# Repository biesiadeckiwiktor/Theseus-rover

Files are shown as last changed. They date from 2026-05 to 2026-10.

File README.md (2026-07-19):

# Theseus Rover

**A low-cost, open-source 6-wheeled rover platform for education, research, and DIY robotics.**

Theseus is inspired by planetary exploration rovers such as ESA's Rosalind Franklin (ExoMars) and CSA's MESR and REX. It can be built entirely from 3D-printed parts and components that are widely available worldwide — no machining or custom PCBs required.

- **Total cost:** under **$800 / £600**, *including* the cost of a 3D printer
- **Two steering configurations:** assemble as 4-wheel-steer (4WS) or 6-wheel-steer (6WS) using the same set of printed parts
- **Modular chassis** built from 2020 aluminium extrusion, so it's easy to extend with sensors, cameras, or a robotic arm

<div align="center">

Theseus rover performing a zero-radius turn
<br><br>
Theseus rover, front three-quarter view
Theseus rover, side view showing suspension

</div>

## Features

- **6-wheel drive** — six JGA25-370 geared DC motors with encoders (one per wheel)
- **4WS / 6WS steering** — four MG996R metal-gear servos steer the corner wheels; differential (Ackermann-style) steering geometry is computed on-board so all wheels track the correct turning radius
- **Zero-radius turning** — spin on the spot at the press of a button
- **Custom handheld transmitter** — dual joysticks, keypad, LCD with live signal strength, and a 3D-printed enclosure (~£76 in parts, design files included); supports the same Wi-Fi / HC-12 dual-mode link as the rover
- **Two radio link options** — control over Wi-Fi (UDP, Pico acts as an access point) or long-range 433 MHz using an HC-12 module; switch with a single flag in the firmware
- **12V LiFePO4 power** with DC-DC converters for logic and servo rails
- **Printable wheels** — uses Lego 32298 tyres, with a fully 3D-printed alternative included (coming soon)

## How it works

```
Theseus transmitter (custom handheld, Pico 2 W)
  dual joysticks · 4x4 keypad · 16x2 LCD · signal & battery indicators
        │
        │  Wi-Fi (UDP) or HC-12 433 MHz radio
        ▼
Raspberry Pi Pico 2 W (on rover)  ──  receives control packets, forwards over UART
        │
        ▼
Arduino Uno R3  ──  decodes packets, computes steering geometry (diffSteer library)
        │
        ├── 2× Adafruit Motor Shields  → 6× DC drive motors
        └── Adafruit 16-ch PWM Shield  → 4× steering servos
```

The `diffSteer` library (in `arduino_code/`) takes the rover's wheelbase and track widths and calculates the individual wheel speeds and steering angles needed for smooth, skid-free turns.

### Control packet format

The transmitter sends an 11-byte packet at ~10 Hz. Anyone can write their own controller (phone app, PC gamepad script, etc.) by sending this frame over UDP to the rover's access point (`192.168.4.1:5005`) or over an HC-12 serial link:

| Byte | Content |
|---|---|
| 0 | Start marker `0xAA` |
| 1–3 | Joystick 1 axes (0–255) |
| 4–6 | Joystick 2 axes (0–255) |
| 7–9 | Button states (24-bit bitmask: 16 keypad keys + 2 joystick buttons) |
| 10 | End marker `0x55` |

## Repository contents

| Path | Description |
|---|---|
| `CAD files/` | All 3D-printable and laser-cut parts in STEP format |
| `arduino_code/` | Arduino Uno firmware: packet decoding, motor/servo control, and the `diffSteer` steering-geometry library |
| `pico_code/` | Raspberry Pi Pico 2 W firmware (MicroPython): Wi-Fi/HC-12 receiver bridge |
| `transmitter/` | Custom handheld transmitter: MicroPython firmware, 3D-printable enclosure (STEP), and its own bill of materials |
| `Bill of materials.xlsx` | Full costed parts list with supplier links |

## The transmitter

Theseus is driven with a purpose-built handheld transmitter (~£76 in parts) rather than an off-the-shelf gamepad:

- **Dual 4-axis joysticks** sampled by two ADS1115 16-bit ADCs over I2C
- **4×4 matrix keypad** for mode switching and auxiliary functions (e.g. zero-turn toggle)
- **16×2 LCD** showing connection status and a live signal-strength bar graph (RSSI)
- **Battery level LEDs** (4-stage indicator)
- **3D-printed enclosure** — CAD in `transmitter/cad/`
- Automatic reconnection if the radio link drops

See `transmitter/bill of materials transmitter.ods` for the full parts list.

## Getting started

### 1. Print and source the parts

Open `Bill of materials.xlsx` for the complete parts list with prices and links. All structural parts in `CAD files/` are provided as STEP files — slice and print them in PLA or PETG. 

All parts were printed with 3 wall loops and 20% infill. 

Structural integrity was tested with static weight of 60kg and no isses were observed, although for normal use up to 15kg is recommended depending on terrain due to limited motor power.

### 2. Assemble

The chassis is built around 2020 aluminium extrusion with printed brackets, joints, and covers. Choose 4WS or 6WS during assembly — both use the same printed parts.

Full assembly guide coming soon

### 3. Flash the firmware

**Raspberry Pi Pico 2 W** (radio receiver):
1. Install MicroPython on the Pico
2. Copy `pico_code/main.py` to the board
3. Set `USE_WIFI = True` for Wi-Fi control or `False` for HC-12

**Arduino Uno** (motion controller):
1. Open `arduino_code/arduino_code.ino` in the Arduino IDE
2. Install the required libraries: `Adafruit Motor Shield V2`, `Adafruit PWM Servo Driver`
3. Upload to the board

### 4. Build and flash the transmitter

1. Source the parts in `transmitter/bill of materials transmitter.ods` (~£76) and print the enclosure from `transmitter/cad/`
2. Install MicroPython on the transmitter's Pico 2 W
3. Install the two required libraries by copying them to the board alongside the code:
   - [`ads1x15`](https://github.com/robert-hh/ads1x15) — driver for the ADS1115 ADCs that read the joysticks
   - [`DIYables_MicroPython_LCD_I2C`](https://github.com/DIYables/DIYables_MicroPython_LCD_I2C) — driver for the 16×2 I2C LCD (also available via Thonny's package manager)
4. Copy `transmitter/code/main.py` to the board
5. Set `USE_WIFI` at the top of the file to match the rover (`True` = Wi-Fi, `False` = HC-12). For Wi-Fi mode, also fill in the rover's IP address

> **Note:** if you use Wi-Fi mode, change the default access point password (`AP_PASSWORD` in `pico_code/main.py` and `PASSWORD` in the transmitter code) — anyone in range who knows the default could connect and send drive commands.

### 5. Drive

Power on the rover, then the transmitter — it connects to the rover's Wi-Fi access point automatically and reconnects if the link drops. One joystick controls speed, the other steering; the keypad handles auxiliary functions such as zero-turn mode.

## Contributing

Contributions, bug reports, and build logs are very welcome! If you build a Theseus, please open an issue or discussion with photos — it helps others and improves the docs.

## License

Code is released under the MIT License. Hardware design files are released under CERN-OHL-P / CC BY-SA 4.0.

## Acknowledgements

Design inspired by ESA's Rosalind Franklin (ExoMars) rover and the Canadian Space Agency's MESR and REX rover prototypes.

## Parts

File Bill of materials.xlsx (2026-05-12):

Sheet: 3-bogie 4WS
Theseus - bill of material | Incl. Shipping, at the time of compiling list
 | Price of individual parts of a kit is calculated as price / number of items
Component | Quantity | Unit price | Price | Comment |  | URL
Wheels
Lego 32298 Tire | 6 | £4.5000 | £27.0000 | 3D printed equivalent provided as alternative, this will reduce number of M3x12 cap srews and M3x4x5 inserts by 60 each |  | https://www.bricklink.com/v2/catalog/catalogitem.page?P=32298#T=S&C=11&O={"color":11,"iconly":0}
Motors
JGA25-370 DC Motor with encoder 6V 60 RPM | 6 | £5.5750 | £33.4500 | higher rpm motors not recommended |  | https://www.aliexpress.com/item/1005008766288833.html
Hex shaft coupling S:12mm L:18mm D:M4 | 6 | £1.1300 | £6.7800 |  |  | https://www.aliexpress.com/item/32794944304.html
Steering
TowerPro Servo Motor - MG996R 180° (Metal Gear) | 4 | £9.0000 | £36.0000 | or equivalent |  | https://thepihut.com/products/towerpro-servo-motor-mg996r-metal-gear-180
Battery
12V 6Ah LiFePO4 Battery | 1 | £19.9900 | £19.9900 | Any battery that fits in boxed volume of 75mm x 190mm x 110mm can be fitted inside the rover with modification to battery compartment
Electronics
Adafruit 16-Channel 12-bit PWM/Servo Shield - I2C interface | 1 | £16.80 | £16.8000 |  |  | https://thepihut.com/products/adafruit-16-channel-12-bit-pwm-servo-shield-i2c-interface
Adafruit Motor/Stepper/Servo Shield for Arduino v3 Kit | 2 | £19.20 | £38.4000 |  |  | https://thepihut.com/products/adafruit-motor-stepper-servo-shield-for-arduino-v2-kit-v2-3
ELEGOO UNO R3 | 1 | £12.10 | £12.1000 |  |  | https://www.amazon.co.uk/ELEGOO-Arduino-Arduino-Compatible-Transfer-Operation/dp/B09JWFTZ2V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
Raspberry Pi Pico 2 W (with headers) | 1 | £7.70 | £7.7000 |  |  | https://thepihut.com/products/raspberry-pi-pico-2-w?variant=54063378760065
High Efficiency Power Module 24V12V to 5V 5A DCDC Stepdown Power Converter | 1 | £5.23 | £5.2300 |  |  | https://www.ebay.co.uk/itm/205165861587?_skw=5v+5a+dcdc+converter&itmmeta=01KKAQXR24Q1MPMFQJWFVYTDKJ
DC-DC Adjustable Step-down Buck Converter Module 12V-75V to 5/24/48V 600W 25A | 1 | £10.9500 | £10.9500 | or equivalent |  | https://www.ebay.co.uk/itm/156755864763
Half-Size Breadboard - White | 1 | £3.0000 | £3.0000 |  |  | https://thepihut.com/products/raspberry-pi-breadboard-half-size
Hardware and fasteners
M3 X 12 Stainless Steel Hex Socket Cap Screw | 60 | £0.0179 | £1.0740 |  |  | https://www.amazon.co.uk/Assortment-Stainless-Replacement-Machine-Fastener/dp/B0B3MGZ7T2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
M3x4x5 threaded insert | 92 | £0.0432 | £3.9714 |  |  | https://www.amazon.co.uk/PATIKIL-Threaded-Knurled-Printing-Components/dp/B0DJ8YBQK8
M3 X 8 Stainless Steel Hex Socket Cap Screw | 16 | £0.0179 | £0.2864 |  |  | https://www.amazon.co.uk/Assortment-Stainless-Replacement-Machine-Fastener/dp/B0B3MGZ7T2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
M3 X 10 Stainless Steel Hex Socket Cap Screw | 44 | £0.0179 | £0.7876 |  |  | https://www.amazon.co.uk/Assortment-Stainless-Replacement-Machine-Fastener/dp/B0B3MGZ7T2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
M3 X 40 Stainless Steel Hex Socket Cap Screw | 4 | £0.0179 | £0.0716 |  |  | https://www.amazon.co.uk/Assortment-Stainless-Replacement-Machine-Fastener/dp/B0B3MGZ7T2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
M3 X 30 Stainless Steel Hex Socket Cap Screw | 16 | £0.0179 | £0.2864 |  |  | https://www.amazon.co.uk/Assortment-Stainless-Replacement-Machine-Fastener/dp/B0B3MGZ7T2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
M3 Nut | 41 | £0.0179 | £0.7339 |  |  | https://www.amazon.co.uk/Assortment-Stainless-Replacement-Machine-Fastener/dp/B0B3MGZ7T2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
Pan Head Brass Screw M4 x 12mm | 6 | £0.0300 | £0.1800 | can be replaced with steel M4x12 |  | https://www.toolstation.com/pan-head-brass-screw/p53904?store=MB&gad_source=1&gad_campaignid=17806929345
M3 X 6 Stainless Steel Hex Socket Cap Screw | 12 | £0.0179 | £0.2148 |  |  | https://www.amazon.co.uk/Assortment-Stainless-Replacement-Machine-Fastener/dp/B0B3MGZ7T2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
Miniature self-tapping crosshead metal screws M1.4 X 5 | 32 | £0.0099 | £0.3171 |  |  | https://www.aliexpress.com/item/1005009816599127.html?pdp_ext_f=%7B"order"%3A"-1"%2C"eval"%3A"1"%2C"fromPage"%3A"search"%7D&pdp_npi=6%40dis%21GBP%2110.39%2110.39%21%21%2194.37%2194.37%21%40210384b917690434802528240eb28d%2112000050263367998%21sea%21UK%216332233678%21X%211%210%21n_tag%3A-29919%3Bd%3A6fe90632%3Bm03_new_user%3A-29895&curPageLogUid=0YpVV11Uw3Cl&utparam-url=scene%3Asearch%7Cquery_from%3A%7Cx_object_id%3A1005009816599127%7C_p_origin_prod%3A
Bearing 25x37x7mm | 8 | £1.5590 | £12.4720 |  |  | https://www.amazon.co.uk/sourcing-map-25x37x7mm-Precision-Lubricated/dp/B0D756WMN6?cv_ct_cx=25id%2Bbearing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
6000-2RS Deep Groove Ball Bearings, ID 10mm x OD 26mm x Width 8mm | 6 | £0.9990 | £5.9940 |  |  | https://www.amazon.co.uk/HiPicco-6000-2RS-Bearings-Bearing-Pre-Lubricated/dp/B0CH2XRNGJ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
2020 aluminium extrusion 1m | 4 | £6.0300 | £24.1200 |  |  | https://www.ebay.co.uk/itm/352816257597?var=622098429634
2020 Cast Aluminium V-Slot Extrusion L Shape Corner Joint Right Angle Bracket-UK | 28 | £0.1838 | £5.1464 |  |  | https://www.ebay.co.uk/itm/227210906598?var=526410016032
M5 Sliding T Nuts | 137 | £0.0869 | £11.9053 |  |  | https://www.amazon.co.uk/PATIKIL-Fastener-European-Standard-Extrusion/dp/B0DS2KLZ5L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
Button Head Screws Hex Allen Socket Bolts Stainless Steel M5x10mm | 56 | £0.0984 | £5.5104 |  |  | https://www.ebay.co.uk/itm/256844204399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
Stainless Steel Washers Flat Heavy Thin Thick Wide M5 | 16 | £0.0425 | £0.6800 |  |  | https://www.ebay.co.uk/itm/167710376070?var=467313689508
Button Head Screws Hex Allen Socket Bolts Stainless Steel M5x16mm | 26 | £0.0984 | £2.5584 |  |  | https://www.ebay.co.uk/itm/256844204399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
Button Head Screws Hex Allen Socket Bolts Stainless Steel M5x8mm | 55 | £0.0984 | £5.4120 |  |  | https://www.ebay.co.uk/itm/256844204399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
2020 Series M3 t Nuts | 18 | £0.0859 | £1.5462 |  |  | https://www.amazon.co.uk/PATIKIL-100pcs-Fastener-Aluminum-Profile/dp/B0DS2JBMHB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
Wiring
25M 22AWG 6 Core Flexible Electrical Extension Cable Wire DC 12V/24V | 1 | £19.9900 | £19.9900 |  |  | https://www.ebay.co.uk/itm/127409063615?var=428503053974
Filament
ELEGOO PLA Filament 1.75mm 4kg | 1 | £33.96 | £33.9600 | or any other filament of choice |  | https://www.amazon.co.uk/ELEGOO-Filament-Dimensional-Accuracy-Cardboard/dp/B0CWNSMRTV
3D printer
Bambu Lab A1 3D Printer | 1 | £209.00 | £209.0000 | or any other printer
Total w/ 3D printer |  |  | £563.6179 | $749.61 | 1600 USD = 1200 GBP
Total w/o 3D printer |  |  | £354.6179 | $471.64 | 1.333333333

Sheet: tools
philips screwdrivers - various sizes
flat screwdriver
multimeter
soldering iron
2.5mm hex key

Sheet: hardware counter
part | parts | per part | total | part
M3x4x5 threaded insert | 6 | 10 | 60 | wheels
 | 4 | 8 | 32 | steering joint base
 |  | Sum | 92
M3x12 | 6 | 10 | 60 | wheels
 |  | Sum | 60
M3x10 | 4 | 8 | 32 | steering joint base
 | 2 | 2 | 4 | middle arm to aluminium extrusion
 | 4 | 2 | 8 | steering joint to aluminium extrusion
 |  | Sum | 44
M3x8 | 4 | 4 | 16 | servo bracket
 |  | Sum | 16
M3 nut | 4 | 4 | 16 | servo bracket
 | 4 | 4 | 16 | steering joint shaft
 | 3 | 3 | 9 | rotating joint
 |  | Sum | 41
M3x40 | 4 | 1 | 4 | steering joint shaft
 |  | Sum | 4
M3x30 | 4 | 4 | 16 | steering joint shaft
 |  | Sum | 16
M3x18 | 3 | 3 | 9 | rotating joint
 |  | Sum | 9
M3x16 | 3 | 2 | 6 | rotating joint
 |  | Sum | 6
Miniature self-tapping crosshead metal screws M1.4 X 5 | 4 | 8 | 32 | servo horn
 |  | Sum | 32
m3x6 | 6 | 2 | 12 | motor to arm
 |  | Sum | 12
m4x12 | 6 | 1 | 6 | wheel to motor
 |  | Sum | 6
m5x16 | 2 | 9 | 18
 | 1 | 8 | 8
 |  | Sum | 26
m5x8 | 3 | 8 | 24
 | 2 | 6 | 12
 | 1 | 19 | 19
 |  | Sum | 55
m5 sliding t nut | 3 | 8 | 24
 | 2 | 6 | 12
 | 1 | 19 | 19
 | 28 | 2 | 56
 | 2 | 9 | 18
 | 1 | 8 | 8
 |  | Sum | 137
m3 hummer nut | 3 | 2 | 6
 | 4 | 2 | 8
 | 2 | 2 | 4
 |  | Sum | 18

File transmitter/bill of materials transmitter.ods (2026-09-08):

Component | Quantity | Unit price | Price | Comment | URL
Wheels
433Mhz HC-12 SI4438 Wireless Serial Port Module | 1 | £6.4900 | £6.4900 |  | https://www.ebay.co.uk/itm/318130640495
ADS1115 4Channel 16-Bit I2C ADC Module with Pro Gain Amplifier | 2 | £3.4950 | £6.9900 |  | https://www.ebay.co.uk/itm/336401136499
Electronic 4- Joystick Potentiometer Button for -D400B- 10K 4D5515 | 2 | £14.3900 | £28.7800 |  | https://www.ebay.co.uk/itm/327126029408?itmmeta=01KXWYQQVDP8VZE8NYPCC85K2P
Raspberry Pi Pico 2 W | 1 | £7.7000 | £7.7000 |  | https://thepihut.com/products/raspberry-pi-pico-2-w
4x4 Matrix Keypad | 1 | £5.0000 | £5.0000 |  | https://thepihut.com/products/4x4-matrix-keypad
16x2 LCD Display LCD1602 Blue Module with I2C | 1 | £4.9900 | £4.9900 |  | https://www.ebay.co.uk/itm/316890449028?_skw=i2c+lcd&itmmeta=01KXWYYV7AJZ3CRYWJ2PJV3KEK
5V 3-15A UBEC Mini External BEC 2-12S Lipo DC-DC Converter Step Down Module | 1 | £5.2300 | £5.2300 |  | https://www.ebay.co.uk/itm/404930399039?var=674967356983
LM3671 3.3V Buck Converter Breakout - 3.3V Output 600mA Max | 1 | £4.8000 | £4.8000 |  | https://thepihut.com/products/adafruit-lm3671-3-3v-buck-converter-breakout-3-3v-output-600ma-max
Small Mini Black On/Off Rocker Switch Rectangle SPST 12V | 1 | £0.7500 | £0.7500 |  | https://www.ebay.co.uk/itm/251390016446?var=550316227968
Diffused 5mm LED Pack - 5 LEDs each in 5 Colors - 25 Pack | 1 | £4.3000 | £4.3000 |  | https://thepihut.com/products/diffused-5mm-led-pack-5-leds-each-in-5-colors-25-pack
Through-Hole Resistors - 220 ohm 5% 1/4W - Pack of 25 | 1 | £0.8000 | £0.8000 |  | https://thepihut.com/products/through-hole-resistors-220-ohm-5-1-4w-pack-of-25
8AA (4+4) Battery Holder | 1 | £5.6900 | £5.6900 |  | https://www.ebay.co.uk/itm/255740327352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
Total |  |  | £81.5200 | $108.42

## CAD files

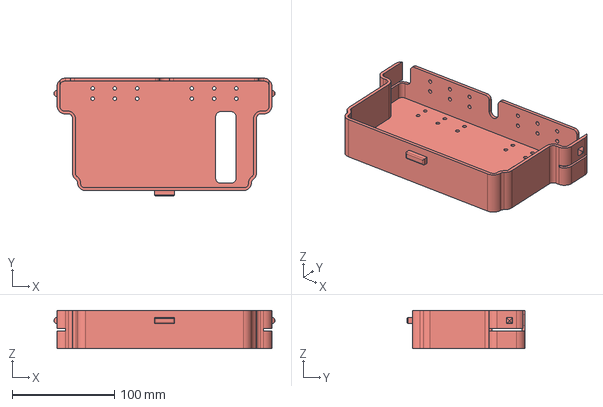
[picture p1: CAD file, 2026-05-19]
CAD files/electronics tray.step
216.0 x 115.0 x 37.5 mm

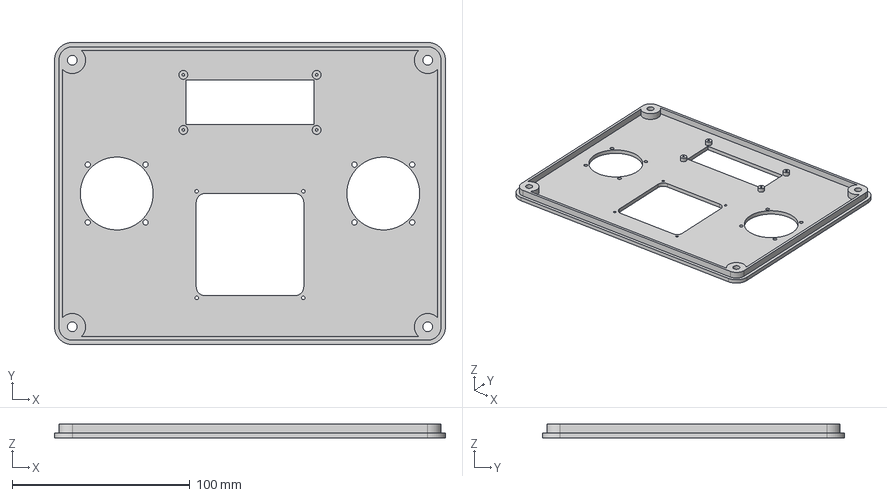
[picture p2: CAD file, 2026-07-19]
transmitter/cad/top plate.step
220.0 x 170.0 x 8.00 mm

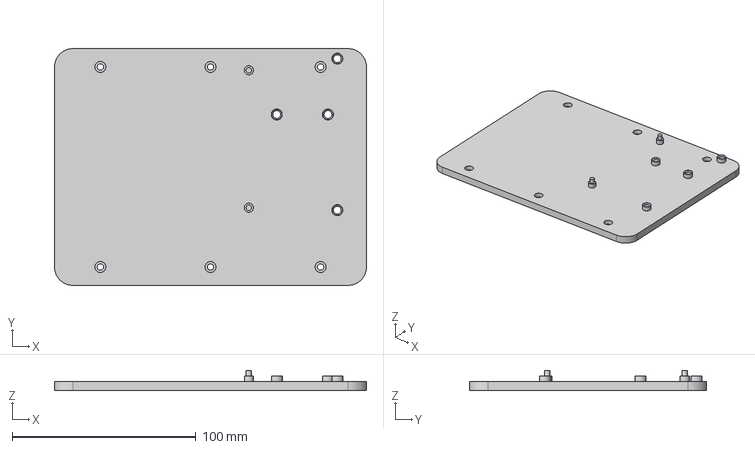
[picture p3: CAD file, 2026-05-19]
CAD files/electronics bracket v2.step
170.0 x 129.0 x 11.0 mm

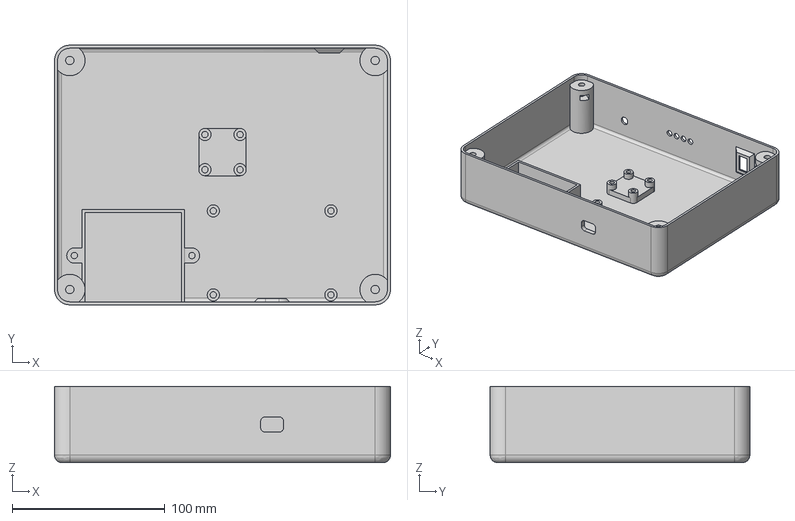
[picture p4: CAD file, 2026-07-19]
transmitter/cad/box.step
220.0 x 170.0 x 50.0 mm

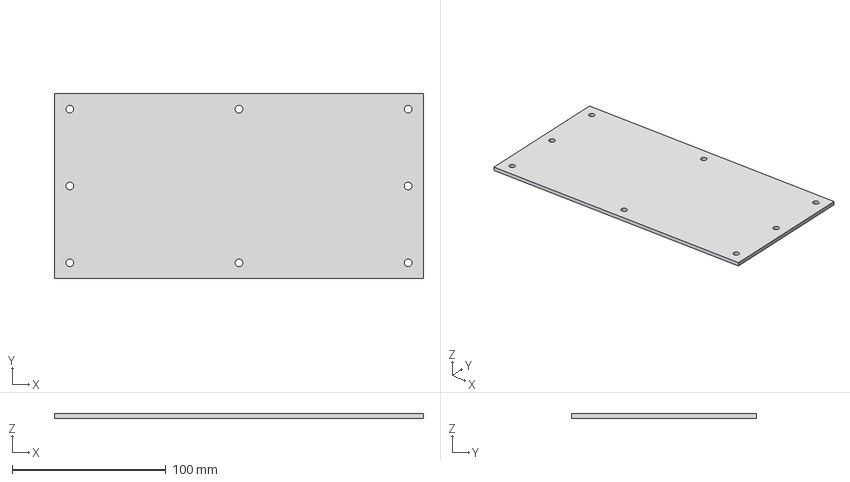
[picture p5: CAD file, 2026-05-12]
CAD files/240x120 acrylic sheet side.step
240.0 x 120.0 x 3.00 mm

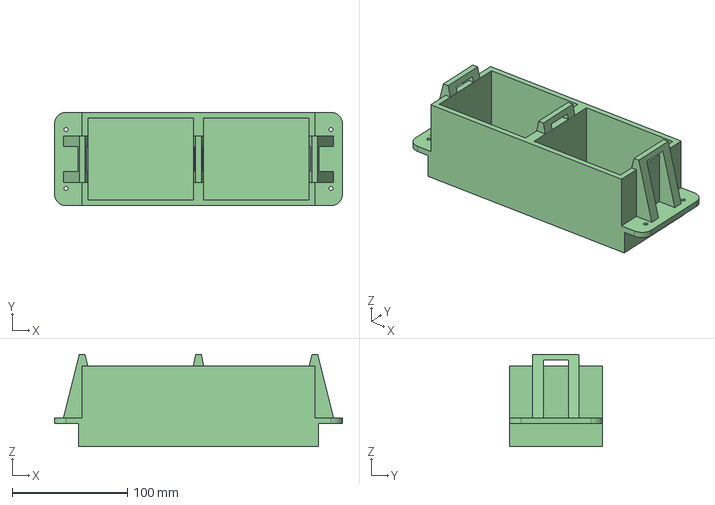
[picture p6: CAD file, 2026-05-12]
CAD files/battery holder.step
250.0 x 81.0 x 80.0 mm

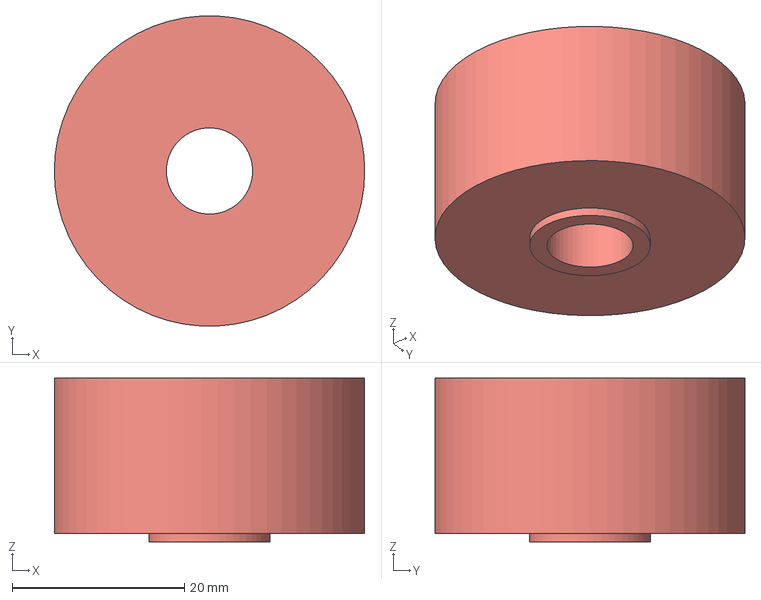
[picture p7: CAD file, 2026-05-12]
CAD files/side spacer.step
36.0 x 35.9 x 19.0 mm

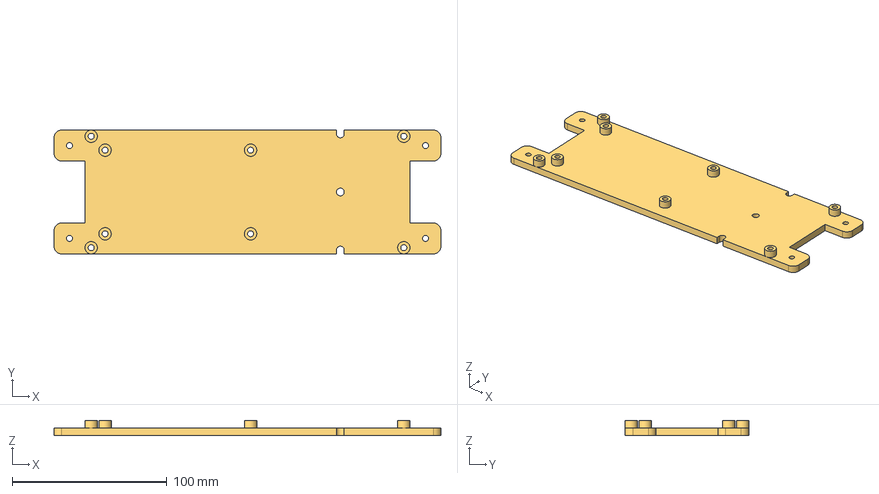
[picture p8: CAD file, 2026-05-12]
CAD files/dc-dc bracket.step
250.0 x 80.0 x 10.0 mm

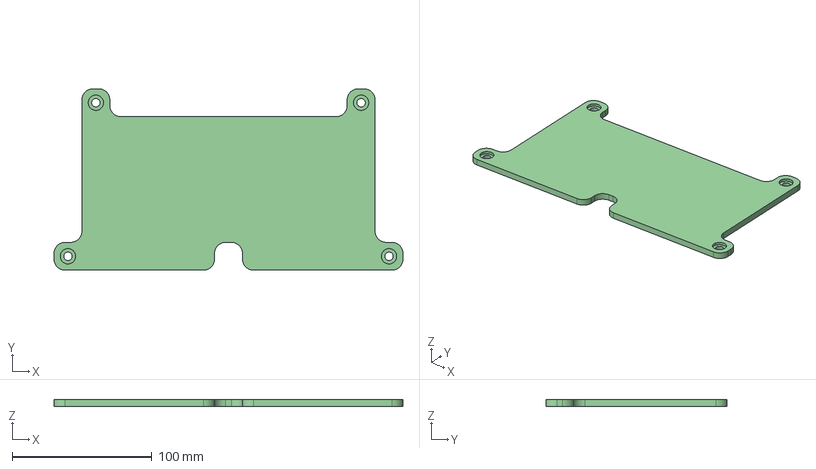
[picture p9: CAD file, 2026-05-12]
CAD files/front cover plate.step
250.0 x 130.0 x 5.00 mm

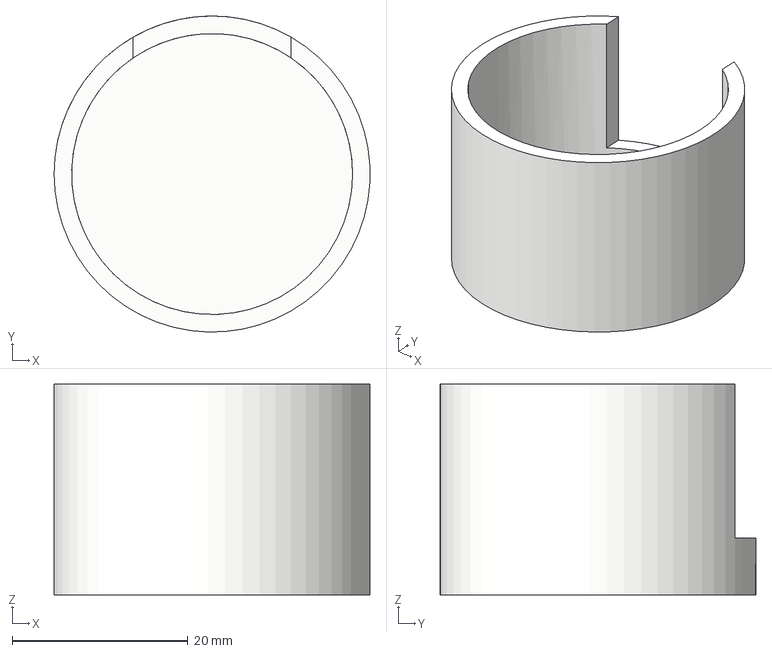
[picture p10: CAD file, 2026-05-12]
CAD files/cover.step
36.0 x 36.0 x 24.0 mm

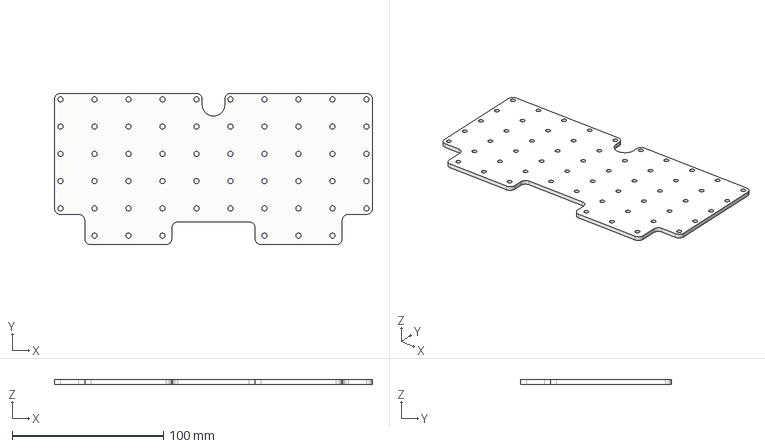
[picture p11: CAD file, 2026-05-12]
CAD files/upper plate.step
210.0 x 100.0 x 3.00 mm

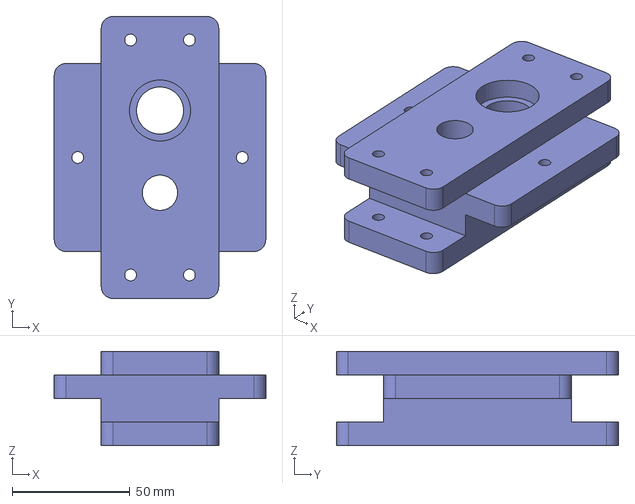
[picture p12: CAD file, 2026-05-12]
CAD files/rear.step
90.0 x 120.0 x 40.0 mm

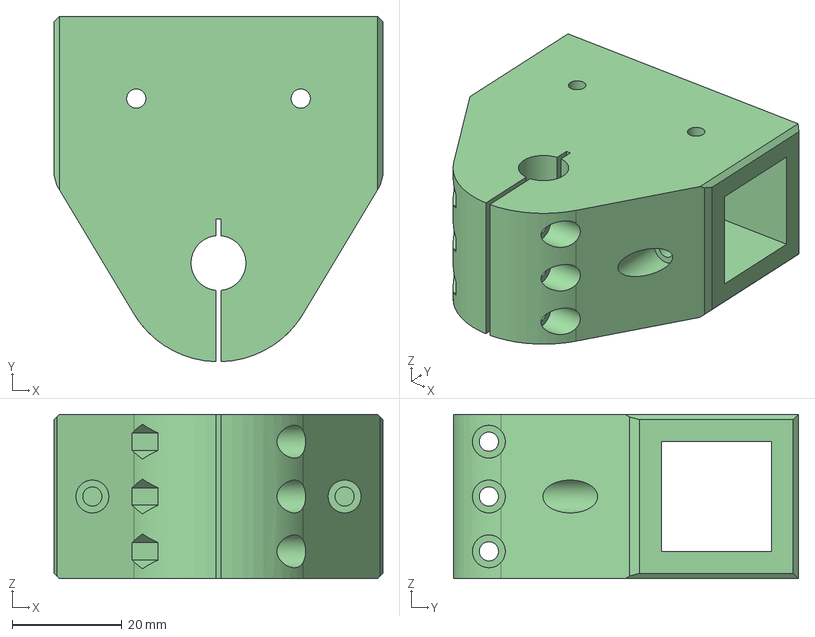
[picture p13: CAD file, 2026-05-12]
CAD files/pivoting joint.step
60.0 x 63.0 x 30.0 mm

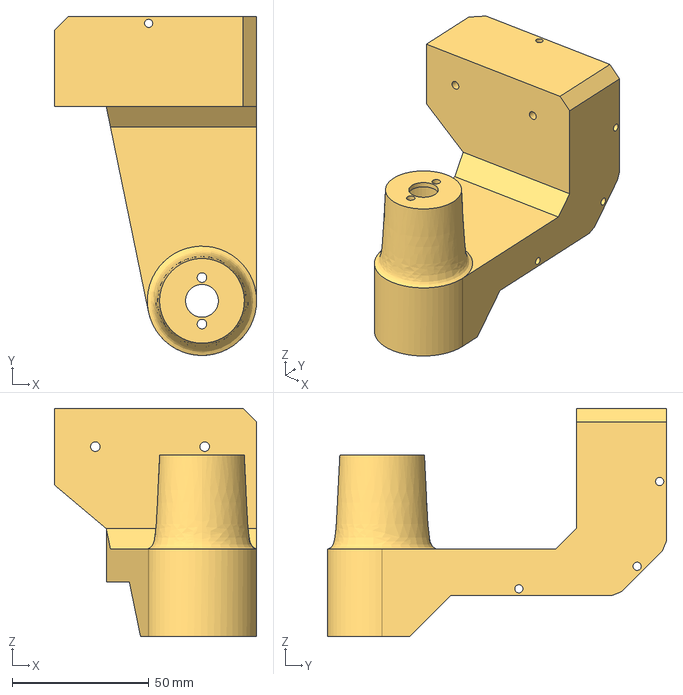
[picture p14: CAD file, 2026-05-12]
CAD files/arm v3.step
74.0 x 124.0 x 83.5 mm

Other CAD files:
CAD files/spacer.step
CAD files/inner rim.step
CAD files/front cover 2.step
CAD files/bottom plate 1.step
CAD files/120x100 rear sheet.step
CAD files/arm v2.step
CAD files/battery terminal.step
CAD files/bottom plate 2.step
CAD files/front spacer.step
CAD files/front travel limited.step
CAD files/middle travel limiter.step
CAD files/pivoting joint 2.step
CAD files/rear travel limiter.step
CAD files/rim edge.step
CAD files/rotating axle.step
CAD files/rotating joint front.step
CAD files/servo bracket.step
CAD files/terminal cover.step
CAD files/to back cover new.step

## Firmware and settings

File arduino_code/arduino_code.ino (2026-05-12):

#include <Wire.h>
#include <Adafruit_MotorShield.h>
#include <Adafruit_PWMServoDriver.h>
#include <SoftwareSerial.h>
#include "diffSteer.h"

SoftwareSerial picoSerial(2, 3);

Adafruit_MotorShield AFMS0 = Adafruit_MotorShield(0x61);
Adafruit_MotorShield AFMS1 = Adafruit_MotorShield(0x60);

Adafruit_PWMServoDriver pwm = Adafruit_PWMServoDriver(0x40);

Adafruit_DCMotor *rear_right = AFMS0.getMotor(2);
Adafruit_DCMotor *middle_right = AFMS0.getMotor(3);
Adafruit_DCMotor *front_right = AFMS0.getMotor(4);
Adafruit_DCMotor *rear_left = AFMS1.getMotor(2);
Adafruit_DCMotor *front_left = AFMS1.getMotor(3);
Adafruit_DCMotor *middle_left = AFMS1.getMotor(4);

#define SERVOMIN 100
#define SERVOMAX 520

#define servo_front_left 13
#define servo_front_right 12
#define servo_rear_left 14
#define servo_rear_right 15

#define servo_front_left_center 355  
#define servo_front_right_center 355  
#define servo_rear_left_center 325    
#define servo_rear_right_center 345       

#define START 0xAA
#define END   0x55
#define PACKET_SIZE 11

enum State { WAIT_START, READ_DATA };
State state = WAIT_START;
byte buf[PACKET_SIZE];
int idx = 0;

byte j1a0, j1a1, j1a2;
byte j2a0, j2a1, j2a2;
long buttons;
bool left_trigger;
bool right_trigger;

bool connected = false;
bool zeroTurn = false;
bool lastButtonState_zeroTurn = false;

unsigned long lastPacketTime = 0;
#define TIMEOUT_MS 500

int lastAngle = 90;

diffSteer steer(427.5, 335.0, 338.0, 335.0);
int sp_fl, sp_fr, sp_ml, sp_mr, sp_rl, sp_rr;


void setup() {
  Serial.begin(9600);
  picoSerial.begin(9600);
 

  if(!pwm.begin()) {
   Serial.println("Could not find Servo Shield. Check wiring.");
    while (1); 
  }
  Serial.println("Servo Shield found.");
  pwm.setPWMFreq(60);

  if (!AFMS0.begin()) {         
    Serial.println("Could not find Motor Shield 1. Check wiring.");
    while (1);
  }
  Serial.println("Motor Shield 1 found.");

  if (!AFMS1.begin()) {         
    Serial.println("Could not find Motor Shield 2. Check wiring.");
    while (1);
  }
  Serial.println("Motor Shield 2 found.");

  servoCenter();
}

void loop() {

  if (connected && (millis() - lastPacketTime > TIMEOUT_MS)) {
        connected = false;
    }

  while (picoSerial.available()) {
    byte b = picoSerial.read();
    //Serial.print("RX: 0x");
     //Serial.println(b, HEX);

      switch (state) {
        case WAIT_START:
          if (b == START) {
            //Serial.println("START found");
            buf[0] = b;
            idx = 1;
            state = READ_DATA;
          }
          break;

        case READ_DATA:
          buf[idx++] = b;
            if (idx == PACKET_SIZE) {
              //Serial.print("END byte: 0x");
              //Serial.println(buf[10], HEX);
              if (buf[10] == END) {
                //Serial.println("valid packet");
                process_packet();
                }
                state = WAIT_START;
                idx = 0;
              }
              break;
      }
  }

  //Serial.print("connected: ");
  //Serial.println(connected);

 if (!connected) {
    rear_right->run(RELEASE);
    middle_right->run(RELEASE);
    front_right->run(RELEASE);
    rear_left->run(RELEASE);
    front_left->run(RELEASE);
    middle_left->run(RELEASE);
    return;
}

bool currentButtonState_zeroTurn = (buttons & (1UL << 17)) != 0;
if (currentButtonState_zeroTurn && !lastButtonState_zeroTurn) {
  zeroTurn = !zeroTurn;
}
lastButtonState_zeroTurn = currentButtonState_zeroTurn;

int speed = 0;

if (zeroTurn) {
  zeroTurnServos();
  if (j1a2 > 140){
    speed = map(j1a2, 140, 255, 0, 255);
    front_left->run(BACKWARD);   front_left->setSpeed(speed);
    front_right->run(FORWARD);  front_right->setSpeed(speed);
    middle_left->run(BACKWARD);  middle_left->setSpeed(speed);
    middle_right->run(FORWARD); middle_right->setSpeed(speed);
    rear_left->run(BACKWARD);    rear_left->setSpeed(speed);
    rear_right->run(FORWARD);   rear_right->setSpeed(speed);

  } else if (j1a2 < 115){
    speed = map(j1a2, 115, 0, 0, 255);
    front_left->run(FORWARD);   front_left->setSpeed(speed);
    front_right->run(BACKWARD);  front_right->setSpeed(speed);
    middle_left->run(FORWARD);  middle_left->setSpeed(speed);
    middle_right->run(BACKWARD); middle_right->setSpeed(speed);
    rear_left->run(FORWARD);    rear_left->setSpeed(speed);
    rear_right->run(BACKWARD);   rear_right->setSpeed(speed);

  } else {
    rear_right->run(RELEASE);
    middle_right->run(RELEASE);
    front_right->run(RELEASE);
    rear_left->run(RELEASE);
    front_left->run(RELEASE);
    middle_left->run(RELEASE);    
  }
} else {
    
    float steerAngle = map(j2a1, 0, 255, 180, 0);  // 90 = straight

    if (j1a0 > 140) {
        speed = map(j1a0, 140, 255, 0, 255);
        steer.calcSpeed(speed, steerAngle, sp_fl, sp_fr, sp_ml, sp_mr, sp_rl, sp_rr);
        front_left->run(FORWARD);   front_left->setSpeed(sp_fl);
        front_right->run(FORWARD);  front_right->setSpeed(sp_fr);
        middle_left->run(FORWARD);  middle_left->setSpeed(sp_ml);
        middle_right->run(FORWARD); middle_right->setSpeed(sp_mr);
        rear_left->run(FORWARD);    rear_left->setSpeed(sp_rl);
        rear_right->run(FORWARD);   rear_right->setSpeed(sp_rr);

    } else if (j1a0 < 115) {
        speed = map(j1a0, 115, 0, 0, 255);
        steer.calcSpeed(speed, steerAngle, sp_fl, sp_fr, sp_ml, sp_mr, sp_rl, sp_rr);
        front_left->run(BACKWARD);   front_left->setSpeed(sp_fl);
        front_right->run(BACKWARD);  front_right->setSpeed(sp_fr);
        middle_left->run(BACKWARD);  middle_left->setSpeed(sp_ml);
        middle_right->run(BACKWARD); middle_right->setSpeed(sp_mr);
        rear_left->run(BACKWARD);    rear_left->setSpeed(sp_rl);
        rear_right->run(BACKWARD);   rear_right->setSpeed(sp_rr);

    } else {
        rear_right->run(RELEASE);
        middle_right->run(RELEASE);
        front_right->run(RELEASE);
        rear_left->run(RELEASE);
        front_left->run(RELEASE);
        middle_left->run(RELEASE);
    }

    if (j2a1 > 140 || j2a1 < 115) {
        int angle = map(j2a1, 255, 0, 0, 180);
        
        if (abs(angle - lastAngle) > 2) {
            lastAngle = angle;
            
            int ang_fl, ang_fr, ang_rl, ang_rr;
            steer.calcSteerAngle(steerAngle, ang_fl, ang_fr, ang_rl, ang_rr);

            pwm.setPWM(servo_front_left,  0, servoAngleToPulse(ang_fl, servo_front_left_center));
            pwm.setPWM(servo_front_right, 0, servoAngleToPulse(ang_fr, servo_front_right_center));
            pwm.setPWM(servo_rear_left,   0, servoAngleToPulse(ang_rl, servo_rear_left_center));
            pwm.setPWM(servo_rear_right,  0, servoAngleToPulse(ang_rr, servo_rear_right_center));
        }
    } else {
        servoCenter();
        lastAngle = 90;
    }
  }



}




/*
convert desired angle into pwn signal
input angle from 0 to 180, 90 is a middle of servo roation 
*/
int servoAngleToPulse(int angle, int center) {
    return constrain(center + angle, SERVOMIN, SERVOMAX);
}
void servoCenter()
{
  pwm.setPWM(servo_front_left, 0, servo_front_left_center);
  pwm.setPWM(servo_front_right, 0, servo_front_right_center);
  pwm.setPWM(servo_rear_left, 0, servo_rear_left_center);
  pwm.setPWM(servo_rear_right, 0, servo_rear_right_center);
}

void process_packet() {
  connected = true;
  lastPacketTime = millis();
  j1a0 = buf[1];
  j1a1 = buf[2];
  j1a2 = buf[3];

  j2a0 = buf[4];
  j2a1 = buf[5];
  j2a2 = buf[6];

  byte btn_low  = buf[7];
  byte btn_mid  = buf[8];
  byte btn_high = buf[9];

   buttons = ((long)btn_high << 16) | ((long)btn_mid << 8) | btn_low;

  left_trigger  = buttons & (1 << 16);
  right_trigger = buttons & (1 << 17);
}

void zeroTurnServos()
{
  pwm.setPWM(servo_front_left,  0, servoAngleToPulse( 100, servo_front_left_center));
  pwm.setPWM(servo_front_right, 0, servoAngleToPulse(-100, servo_front_right_center));
  pwm.setPWM(servo_rear_left,   0, servoAngleToPulse(-100, servo_rear_left_center));
  pwm.setPWM(servo_rear_right,  0, servoAngleToPulse( 100, servo_rear_right_center));
}

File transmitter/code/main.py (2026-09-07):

from machine import Pin, I2C, ADC, UART
from DIYables_MicroPython_LCD_I2C import LCD_I2C
import time
import ads1x15
import struct

# ---- COMMUNICATION MODE ----
USE_WIFI = False  # True = WiFi, False = HC-12
# ----------------------------

START = 0xAA
END = 0x55

i2c0 = I2C(1, scl=Pin(3), sda=Pin(2), freq=400000)
i2c1 = I2C(0, scl=Pin(5), sda=Pin(4), freq=400000)

I2C_ADDR = 0x27
LCD_ROWS = 2
LCD_COLS = 16

lcd = LCD_I2C(i2c0, I2C_ADDR, LCD_ROWS, LCD_COLS)

ads0 = ads1x15.ADS1115(i2c1, 0x48)
ads1 = ads1x15.ADS1115(i2c1, 0x49)

red = Pin(18, Pin.OUT)
yellow_1 = Pin(19, Pin.OUT)
yellow_2 = Pin(20, Pin.OUT)
green = Pin(21, Pin.OUT)

if USE_WIFI:
    import network
    import socket
    SSID = "theseus"
    PASSWORD = "12345678"
    IP = "###.###.#.#" #replace
    PORT = 5005
    wifi = network.WLAN(network.STA_IF)
    wifi.active(True)
    sock = socket.socket(socket.AF_INET, socket.SOCK_DGRAM)
else:
    hc12 = UART(0, baudrate=9600, tx=Pin(16), rx=Pin(17))

time.sleep(2)

lcd.print("Hello :)")

red(1)
yellow_1(1)
yellow_2(1)
green(1)

row_pins = [Pin(p, Pin.IN, Pin.PULL_DOWN) for p in (6,7,8,9)]
col_pins = [Pin(p, Pin.OUT) for p in (10,11,12,13)]

adc = ADC(Pin(28))

key_map = (
    (1,4,7,"*"),
    (2,5,8,"0"),
    (3,6,9,"#"),
    ("A","B","C","D")
)

key_to_bit = {
    1:0, 2:1, 3:2,
    4:3, 5:4, 6:5,
    7:6, 8:7, 9:8,
    "0":9, "*":10, "#":11,
    "A":12, "B":13, "C":14, "D":15
}

buttonL = Pin(14, Pin.IN, Pin.PULL_UP)
buttonR = Pin(15, Pin.IN, Pin.PULL_UP)

red(0)
yellow_1(0)
yellow_2(0)
green(0)

def scan_keypad():
    for c, col in enumerate(col_pins):
        col.on()
        for r, row in enumerate(row_pins):
            if row.value():
                col.off()
                return key_map[r][c]
        col.off()
    return None

def read_voltage(adc, ch):
    raw = adc.read(4, ch)
    return adc.raw_to_v(raw)

def voltage_to_byte(v):
    v = max(0, min(3.3, v))
    return int(v / 3.3 * 255)

def map_value(x, in_min, in_max, out_min, out_max):
    return (x - in_min) * (out_max - out_min) / (in_max - in_min) + out_min

def connect_wifi():
    if wifi.isconnected():
        return True
    print("Connecting wifi...")
    lcd.clear()
    lcd.print("Connecting wifi...")
    try:
        wifi.disconnect()
    except:
        pass
    time.sleep(2)
    wifi.connect(SSID, PASSWORD)
    timeout = 20
    while not wifi.isconnected() and timeout > 0:
        time.sleep(1)
        timeout -= 1
    if wifi.isconnected():
        lcd.clear()
        lcd.print("Connected")
        return True
    else:
        lcd.clear()
        lcd.print("Failed")
        return False

def rssi_to_bars(rssi):
    if rssi >= -50: return 8
    elif rssi >= -55: return 7
    elif rssi >= -60: return 6
    elif rssi >= -65: return 5
    elif rssi >= -70: return 4
    elif rssi >= -75: return 3
    elif rssi >= -80: return 2
    else: return 1

def show_signal(rssi):
    lcd.clear()
    bars = rssi_to_bars(rssi)
    lcd.set_cursor(0, 0)
    lcd.print("{:4d}dB".format(rssi))
    for i in range(8):
        lcd.set_cursor(8 + i, 0)
        lcd.print(chr(signal_top[bars - 1][i]))
    for i in range(8):
        lcd.set_cursor(8 + i, 1)
        lcd.print(chr(signal_bot[bars - 1][i]))

signal = 0
last_key = None

p0 = [0b00000]*8
p20 = [0,0,0,0,0,0,0b11111,0b11111]
p40 = [0,0,0,0,0b11111,0b11111,0b11111,0b11111]
p60 = [0,0,0b11111,0b11111,0b11111,0b11111,0b11111,0b11111]
p80 = [0b11111]*8

lcd.custom_char(0, p0)
lcd.custom_char(1, p20)
lcd.custom_char(2, p40)
lcd.custom_char(3, p60)
lcd.custom_char(4, p80)

signal_bot = [
    [1,0,0,0,0,0,0,0],
    [1,2,0,0,0,0,0,0],
    [1,2,3,0,0,0,0,0],
    [1,2,3,4,0,0,0,0],
    [1,2,3,4,4,0,0,0],
    [1,2,3,4,4,4,0,0],
    [1,2,3,4,4,4,4,0],
    [1,2,3,4,4,4,4,4],
]

signal_top = [
    [0,0,0,0,0,0,0,0],
    [0,0,0,0,0,0,0,0],
    [0,0,0,0,0,0,0,0],
    [0,0,0,0,0,0,0,0],
    [0,0,0,0,1,0,0,0],
    [0,0,0,0,1,2,0,0],
    [0,0,0,0,1,2,3,0],
    [0,0,0,0,1,2,3,4],
]

if USE_WIFI:
    while not connect_wifi():
        time.sleep(2)

last_key = None

while True:

    adc_value = adc.read_u16() >> 4
    voltage = map_value(adc_value, 0, 4095, 0, 3.3)

    if voltage > 2.8:
        red.on(); yellow_1.on(); yellow_2.on(); green.on()
    elif 2.8 >= voltage > 2.6:
        red.on(); yellow_1.on(); yellow_2.on(); green.off()
    elif 2.6 >= voltage > 2.4:
        red.on(); yellow_1.on(); yellow_2.off(); green.off()
    else:
        red.on(); yellow_1.off(); yellow_2.off(); green.off()

    if USE_WIFI and not wifi.isconnected():
        lcd.clear()
        lcd.print("Signal lost")
        while not connect_wifi():
            time.sleep(2)
        continue

    v0 = read_voltage(ads0, 0)
    v1 = read_voltage(ads0, 1)
    v2 = read_voltage(ads0, 2)
    v3 = read_voltage(ads1, 0)
    v4 = read_voltage(ads1, 1)
    v5 = read_voltage(ads1, 2)

    j1a0 = voltage_to_byte(v0)
    j1a1 = voltage_to_byte(v1)
    j1a2 = voltage_to_byte(v2)
    j2a0 = voltage_to_byte(v3)
    j2a1 = voltage_to_byte(v4)
    j2a2 = voltage_to_byte(v5)

    buttons = 0

    key = scan_keypad()
    if key and key != last_key:
        print("Pressed:", key)
    if key in key_to_bit:
        buttons |= (1 << key_to_bit[key])
    last_key = key

    if not buttonL.value():
        buttons |= (1 << 16)
    if not buttonR.value():
        buttons |= (1 << 17)

    btn_low  = buttons & 0xFF
    btn_mid  = (buttons >> 8) & 0xFF
    btn_high = (buttons >> 16) & 0xFF

    packet = struct.pack(
        "BBBBBBBBBBB",
        START,
        j1a0, j1a1, j1a2,
        j2a0, j2a1, j2a2,
        btn_low, btn_mid, btn_high,
        END
    )

    if USE_WIFI:
        try:
            sock.sendto(packet, (IP, PORT))
        except:
            pass
        rssi = wifi.status('rssi')
        # show_signal(rssi)  # re-enable if needed
    else:
        hc12.write(packet)
        print("Sent:", packet)

    time.sleep(0.1)

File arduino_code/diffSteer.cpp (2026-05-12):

#include "Arduino.h"
#include "diffSteer.h"
#include <math.h>

diffSteer::diffSteer(float wheelBase, float trackWidth_f, float trackWidth_m, float trackWidth_r)
{
  _wheelBase = wheelBase;
  _trackWidth_f = trackWidth_f;
  _trackWidth_m = trackWidth_m;
  _trackWidth_r = trackWidth_r;
}

void diffSteer::calcSpeed(float speed, float angle, int &fl, int &fr, int &ml, int &mr, int &rl, int &rr)
{
  if (abs(angle - 90.0) < 1.0)
  {
    fl = fr = ml = mr = rl = rr = (int)speed;
    return;
  }

  angle = constrain(angle, 30, 150);

  float delta = radians(angle - 90.0);  
  float tanDelta = tan(delta);

  float R = _wheelBase / tanDelta;

  float r_fl = sqrt(pow(R + _trackWidth_f / 2.0f, 2) + pow(_wheelBase / 2.0f, 2));
  float r_fr = sqrt(pow(R - _trackWidth_f / 2.0f, 2) + pow(_wheelBase / 2.0f, 2));
  float r_ml = sqrt(pow(R + _trackWidth_m / 2.0f, 2) + pow(_wheelBase / 2.0f, 2));
  float r_mr = sqrt(pow(R - _trackWidth_m / 2.0f, 2) + pow(_wheelBase / 2.0f, 2));
  float r_rl = sqrt(pow(R + _trackWidth_r / 2.0f, 2) + pow(_wheelBase / 2.0f, 2));
  float r_rr = sqrt(pow(R - _trackWidth_r / 2.0f, 2) + pow(_wheelBase / 2.0f, 2));

  //Serial.print("r_fl="); Serial.println(r_fl);
  //Serial.print("r_fr="); Serial.println(r_fr);
  //Serial.print("r_ml="); Serial.println(r_ml);
  //Serial.print("r_mr="); Serial.println(r_mr);
  //Serial.print("r_rl="); Serial.println(r_rl);
  //Serial.print("r_rr="); Serial.println(r_rr);


  float r_max = max(r_fl, max(r_fr, max(r_rl, r_rr)));

  float v_fl = speed * r_fl / r_max;
  float v_fr = speed * r_fr / r_max;
  float v_rl = speed * r_rl / r_max;
  float v_rr = speed * r_rr / r_max;

  float v_left  = (v_fl + v_rl) / 2.0f;
  float v_right = (v_fr + v_rr) / 2.0f;

  fl = rl = (int)constrain(v_left,  0, 255);
  fr = rr = (int)constrain(v_right, 0, 255);

  ml = (int)constrain(v_left  * r_ml / r_fl, 0, 255);
  mr = (int)constrain(v_right * r_mr / r_fr, 0, 255);
}

void diffSteer::calcSteerAngle(float angle, int &s_fl, int &s_fr, int &s_rl, int &s_rr)
{
  if (abs(angle - 90.0) < 1.0)
  {
    s_fl = s_fr = s_rl = s_rr = 0;
    return;
  }

  angle = constrain(angle, 30, 150);

  float delta    = radians(angle - 90.0); 
  float tanDelta = tan(delta);

  float deltaL = atan(_wheelBase * tanDelta / (_wheelBase + 0.5f * _trackWidth_f * tanDelta));
  float deltaR = atan(_wheelBase * tanDelta / (_wheelBase - 0.5f * _trackWidth_f * tanDelta));

  s_fl = (int)degrees(deltaL);
  s_fr = (int)degrees(deltaR);
  s_rl = -(int)degrees(deltaL);   
  s_rr = -(int)degrees(deltaR);
}

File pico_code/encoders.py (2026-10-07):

'''
encoders.py - quadrature encoder reader using PIO
Adapted from:
SPDX-FileCopyrightText: 2022 Jamon Terrell <github@jamonterrell.com>
SPDX-License-Identifier: MIT
https://github.com/jamon/pi-pico-pio-quadrature-encoder/blob/main/python/quadrature.py

Changes include fifo cleanup and initialising pull up on encoder pins to high by default 
'''
from rp2 import PIO, StateMachine, asm_pio
from machine import Pin


@asm_pio(autopush=True, push_thresh=32)
def _encoder_pio():
    wait(0, pin, 0)
    jmp(pin, "WAIT_HIGH")
    mov(x, invert(x))
    jmp(x_dec, "nop1")
    label("nop1")
    mov(x, invert(x))
    label("WAIT_HIGH")
    jmp(x_dec, "nop2")
    label("nop2")
    wait(1, pin, 0)
    jmp(pin, "WAIT_LOW")
    jmp(x_dec, "nop3")
    label("nop3")
    label("WAIT_LOW")
    mov(x, invert(x))
    jmp(x_dec, "nop4")
    label("nop4")
    mov(x, invert(x))
    wrap()


class Encoder:
    def __init__(self, sm_id, clk_pin, data_pin):
        Pin(clk_pin, Pin.IN, Pin.PULL_UP)
        Pin(data_pin, Pin.IN, Pin.PULL_UP)
        self._sm = StateMachine(
            sm_id, _encoder_pio, freq=125_000_000,
            in_base=Pin(clk_pin), jmp_pin=Pin(data_pin)
        )
        self._sm.active(1)

    def read(self):
        while self._sm.rx_fifo():          
            self._sm.get()
        self._sm.exec("in_(x, 32)")
        x = self._sm.get()
        return x if x < 0x80000000 else x - 0x100000000

    def stop(self):
        self._sm.active(0)

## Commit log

2026-05-12 update 12/05/26
    [120x100 rear sheet.step, 240x120 acrylic sheet side.step, Bill of materials.xlsx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]
2026-05-19 19/05/26
    Electronics rearranged to allow MEGA boards and Raspberry PI to be mounted inside the body.
    [electronics bracket v2.step, electronics bracket.step, electronics tray.step]
2026-07-19 transmitter upload
    [bill of materials transmitter.ods, box.step, top plate.step]
2026-09-08 Updated bom
    [bill of materials transmitter.ods]
2026-10-07 Added encoders
